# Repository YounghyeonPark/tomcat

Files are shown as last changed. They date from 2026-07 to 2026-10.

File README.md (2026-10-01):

# Project T.O.M.C.A.T.

**Tendon-Operated Mechanism for a Compliant Actuated Tomcat** — an open,
cat-sized quadruped whose joints are pulled by cables from motors in the body,
not driven by a motor at each joint.



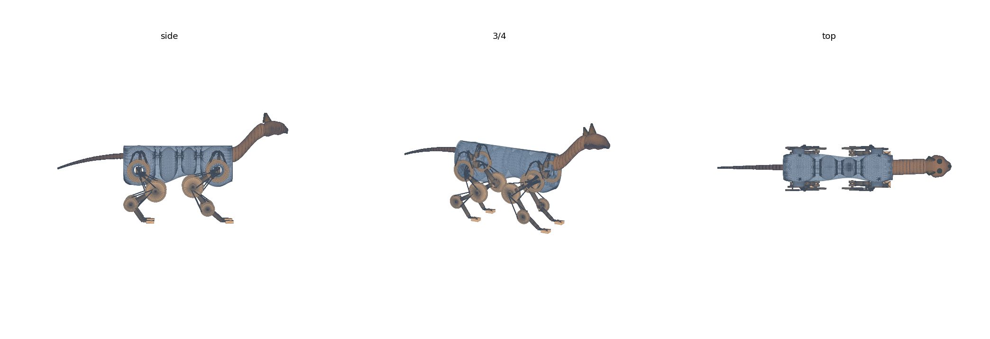
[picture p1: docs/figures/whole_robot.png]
the whole robot


## How a leg is driven

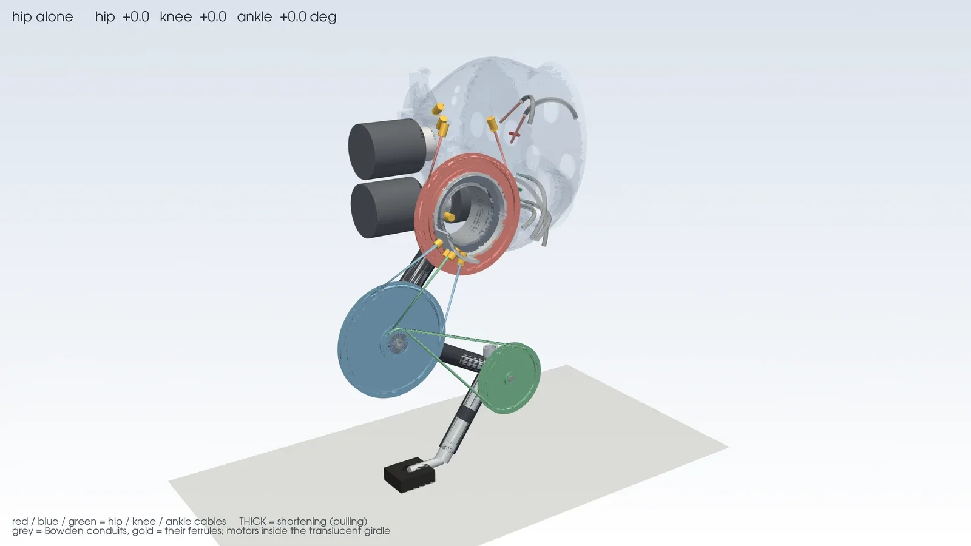
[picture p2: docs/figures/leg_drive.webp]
a hind leg's drive, in 3-D


Each joint is an antagonistic cable pair wound on one spool, so one motor
drives one joint both ways (red / blue / green = hip / knee / ankle; thick =
the cable pulling).

- **Motors in the body.** Each girdle holds its leg motors in two rows that
  straddle the hip, spools facing across it ([ADR-0114](docs/DESIGN_DECISIONS.md)).
- **Knee and ankle cables run along the hip axis**, through a hollow hip: the
  trunk carries a stub, the femur turns on it in two bearings, and the cables
  never cross the femur's path.
- **Bowden conduits** carry each cable from the body to the leg; friction is
  charged where the cable slides ([ADR-0112](docs/DESIGN_DECISIONS.md)).
- **A series spring (G3)** sits between each motor and its spool: a titanium
  planar flexure, 125 kN/m on the legs and 350 kN/m on the spine
  ([ADR-0107](docs/DESIGN_DECISIONS.md), [ADR-0117](docs/DESIGN_DECISIONS.md)).
- **An articulated, cable-driven spine** (3 segments, pitch and yaw) does the
  balancing sway and the mid-air righting.

| One leg, as parts | The trunk: 19 motors in four rigid bodies |
|---|---|
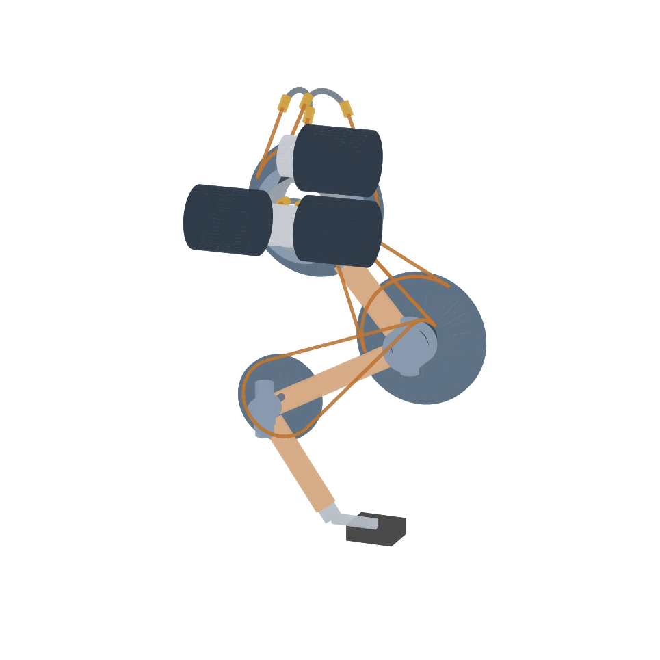
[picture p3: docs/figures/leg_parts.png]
leg detail
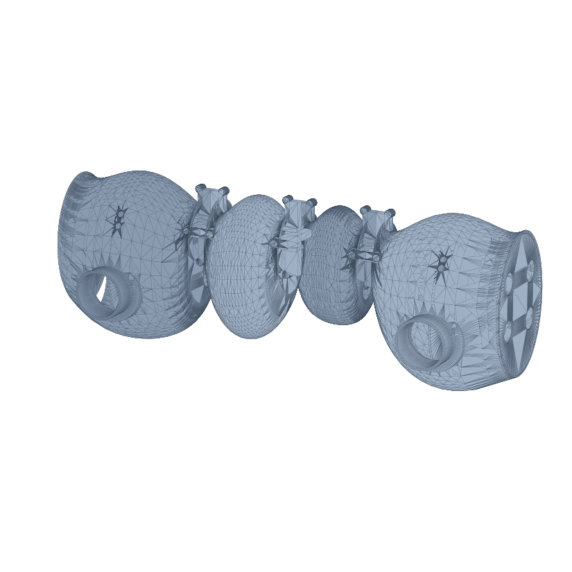
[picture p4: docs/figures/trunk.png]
trunk
|  |  |

## Key numbers

| | |
|---|---|
| Mass | **4.58 kg** (19 motors: 12 leg, 6 spine, 1 tail) |
| Trunk / hips apart | 372 mm / 270 mm |
| Joint moment arms (hip / knee / ankle) | 36 / 34 / 22 mm |
| Motor demand (peak / continuous) | 1.65 / 0.57 N·m per motor |
| Trot | 50 cm/s |
| Runtime, trotting | 18–24 min (~710 m) on a 300 g pack |
| Righting from upside down | ~1.0 s (simulated) |

Every number is computed from the live model, not typed in: the CAD, the
MuJoCo plant and the budgets all read `kinematics/src/tomcat_kin/params.py`.

## Status

**Modelling and design — no hardware built.** What is still uncertain, and
what closes it, is in [OPEN_RISKS.md](docs/OPEN_RISKS.md). The largest open
items: the motor (a GIM3505-9 is a proxy for size and mass; the spec it must
meet is in ADR-0100/0110), bench values for conduit friction and the G3 rates,
and a mock-up of the cable bundle that twists inside the hollow hip.

## Repository

| Path | Contents |
|---|---|
| `kinematics/` | `tomcat_kin`: kinematics, tendon maps, mass, gait, balance, MuJoCo plants, RL env |
| `mechanical/cad/` | build123d CAD: trunk, legs, hollow hip, drive, G3 flexure, head, tail, skin |
| `thermal/` | Rust crate: motor and girdle thermal duty |
| `tests/` | pytest suite (556 tests) |
| `docs/` | requirements, architecture, the ADR log, the progress log |
| `electronics/`, `firmware/` | not started |

```bash
pip install numpy pytest mujoco gymnasium build123d vtk matplotlib pillow
pytest tests --ignore=tests/test_mjcf_tendon.py   # conftest.py puts kinematics/src on the path
cd thermal && cargo test
python mechanical/cad/tomcat_assembly.py --render   # the whole-robot picture
python mechanical/cad/leg_drive_3d.py --hq          # the drive animation (1600x900, 30 fps)
```

> ⚠️ `tests/test_mjcf_tendon.py` needs ~19 GB as one process — run it in
> slices. The whole-robot render needs ~12 GB.

## Documents

- [Design decisions (ADR log)](docs/DESIGN_DECISIONS.md) — every choice, and why
- [Progress log](docs/PROGRESS.md) — the milestone-by-milestone record
- [Requirements](docs/REQUIREMENTS.md) · [Architecture](docs/ARCHITECTURE.md) ·
  [Principles](docs/PRINCIPLES.md) · [Open risks](docs/OPEN_RISKS.md)
- [Literature review](docs/LITERATURE_REVIEW.md) · [References](docs/REFERENCES.md) ·
  [Glossary](docs/GLOSSARY.md)

## License

[Apache License 2.0](LICENSE). The feline skeletal geometry derives from
Reighard & Jennings, *Anatomy of the Cat* (1901), public domain; third-party
material is listed in [NOTICE](NOTICE).

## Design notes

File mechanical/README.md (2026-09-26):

# mechanical/

Mechanical design for TomCat: leg geometry, joint/pulley design, tendon routing,
and bill of materials.

Scope:
- **Skeleton:** an articulated tendon-driven spine + 4 legs, 3 DOF each (hip,
  knee, ankle). The torso is *not* rigid — see [ADR-0006](../docs/DESIGN_DECISIONS.md)
  and NFR1/NFR2 in [../docs/REQUIREMENTS.md](../docs/REQUIREMENTS.md).
- **Spine:** serial segments allowing dorsoventral + lateral bend (and, ideally,
  axial twist for the righting reflex), with tendons routed to girdle motors.
- **Tail:** a **single-tendon** appendage — tension to curl/raise, loosen to
  relax (passive return); no precision (see [ADR-0007](../docs/DESIGN_DECISIONS.md)).
  Coarse inertial assist only — righting authority is in the spine + legs.
- **Tendon routing:** cable paths from torso-mounted motors over pulleys to each
  joint; sheaths, anchor points, and moment arms.
- **Compliance:** return springs and/or series-elastic elements per ADR-0002.
- **BOM:** motors, cables, pulleys, bearings, springs, fasteners.

## Review
- [DESIGN_REVIEW.md](DESIGN_REVIEW.md) — **first critical pass** over the whole
  mechanical design. Five findings, three major: the mass apportionment
  contradicts P1 (limbs over-budgeted, girdles under-budgeted), the 60/40
  front-heavy split is likely wrong once motors sit in their real clusters
  (which would move the M4 stability margins), and the **links are never
  structurally sized** — the femur sits at SF ≈ 1.0 in bending from its own
  offset tendon.

## Reference
- [reference/ANATOMY.md](reference/ANATOMY.md) — feline anatomy basis for the
  biomimetic geometry, citing **public-domain** sources (Reighard & Jennings,
  *Anatomy of the Cat*, 1901) — vertebral formula, digitigrade limbs, fore/hind
  asymmetry, thorax vs lumbar.

## CAD
- [cad/](cad/) — the build123d model, driven by `tomcat_kin`'s parameters: the
  whole robot (`tomcat_assembly.py`), the trunk with its 19 motors
  (`tomcat_trunk.py`), one leg as manufacturable parts (`tomcat_leg_detail.py`,
  STEP), the G3 flexure (`g3_flexure.py`, STEP), head, tail and skin. The first
  skeleton and packaging studies are kept there as history.

## Specs
- [ASSEMBLY_SPEC.md](ASSEMBLY_SPEC.md) — **how it is built**: fabrication method
  per part, joint assembly stack-up and fits, cable termination and
  re-tensioning access, assembly sequence. Also closes the combined
  bending+torsion and local-crushing checks (review F3/F5).
- [LEG_TENDON_SPEC.md](LEG_TENDON_SPEC.md) — leg tendon-drive spec for the
  pure-tendon legs (ADR-0003): moment-arm sizing that halves the ~1 kN cable
  tension to a ~500 N land transient, UHMWPE cable spec, pulley/bearing/routing
  and wrap angles (capstan friction), a static-hold brake, and the parameter
  table for `LegParams` / `TendonParams`.
- [SPINE_TAIL_SPEC.md](SPINE_TAIL_SPEC.md) — first-pass geometry & tendon-routing
  proposal for the 3-segment articulated spine (ADR-0006) and the single-tendon
  tail (ADR-0007): segment lengths, girdle placement, routing paths, moment arms,
  per-axis ROM, and the parameter table for `SpineParams` + `TailParams`, plus
  BOM/motor-count implications.

- [TACTILE_SENSING_SPEC.md](TACTILE_SENSING_SPEC.md) — **contact sensing and the
  paw structure** (ADR-0012), the prerequisite for closed-loop balance. Derives
  the force range, bandwidth and — the binding one — the **20 g/paw** distal-mass
  limit from the robot's own swing dynamics, and shows why the existing joint-end
  load cells cannot substitute.

## Status
Stub — CAD files and routing diagrams to be added. Mechanical review is the
gate for ADR-0002 (antagonistic vs. return spring) and torque budget feeding
ADR-0003 (actuator choice).

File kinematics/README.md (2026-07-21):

# kinematics/

Kinematics models, tendon mapping, and gait planning for TomCat.

Responsibilities (see [../docs/ARCHITECTURE.md](../docs/ARCHITECTURE.md)):
- **Leg kinematics:** forward/inverse kinematics (foot position ↔ joint angles).
- **Tendon map:** joint angle & stiffness ↔ per-motor cable length + tension,
  including moment arms (pulley radii), friction, and finite cable stiffness.
- **Antagonistic coordination:** split desired joint torque/stiffness across
  opposing tendons (or tendon + return spring) — see ADR-0002.
- **Gait planning:** foot/body trajectories for walk, trot, etc.

## Layout
- `src/tomcat_kin/` — the prototype package:
  - `params.py` — placeholder geometry / mass / tendon parameters (all TBD).
  - `leg.py` — planar 3R leg: FK, IK (both knee branches), Jacobian.
  - `tendon.py` — tendon map: angle↔cable, torque↔tension; antagonistic and
    spring-return modes (ADR-0002).
  - `torque_budget.py` — static worst-case joint/tendon/motor torque sweep.
- `demo.py` — runnable end-to-end example.
- Tests live in [../tests/](../tests) (`test_leg.py`, `test_tendon.py`).

## Run it
```
python kinematics/demo.py     # FK/IK round-trip, tendon resolve, torque budget
python -m pytest -q           # 17 tests (run from repo root)
```

## Status
Working single-leg prototype. **All parameters in `params.py` are placeholders**
— the torque-budget magnitudes are illustrative only until mechanical design
lands. The workspace sweep is also limited by the placeholder joint limits
(foot pitch is held at 0), so only part of the reachable area is currently
in-limit; revisit once real joint ranges exist.

Next steps: an articulated **spine model** (per [ADR-0006](../docs/DESIGN_DECISIONS.md))
so the leg base can curve, whole-body kinematics on top of it, a 3D
(frontal-plane abduction) leg, gait trajectory generation, and validating the
tendon map against measured cable friction/stretch.

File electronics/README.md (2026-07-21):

# electronics/

KiCad schematics and PCB layout for the TomCat control electronics.

Planned boards (see [../docs/ARCHITECTURE.md](../docs/ARCHITECTURE.md)):
- **Control board:** main compute / RT-MCU, IMU, host link, power regulation,
  e-stop.
- **Motor driver stage(s):** power stage per motor with current sensing;
  count depends on total DOF and antagonistic choice (ADR-0002).
- **Sensor conditioning:** tendon tension (load-cell amp) and joint-angle
  front-ends, per ADR-0004.

## Tooling
This repo has a `kicad-cli` skill available for ERC/DRC checks and BOM/Gerber
export once schematics exist. Read the skill's "Project gotchas" section before
trusting CLI ERC/netlist results.

## Status
Stub — no schematics yet. Blocked on actuator and sensing decisions
(ADR-0003, ADR-0004).

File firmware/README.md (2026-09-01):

# firmware/

Embedded control firmware for TomCat.

Responsibilities (see [../docs/ARCHITECTURE.md](../docs/ARCHITECTURE.md)):
- **Low-level (≥1 kHz):** per-motor position + tension control loops, safety
  limits (over-current, over-tension, thermal, e-stop → limp).
- **Sensor sampling:** motor current/encoder, tendon tension, joint angle, IMU,
  foot contact.
- **Comms:** telemetry up to the planner/host; setpoints down to motor loops.

> ⚠️ **"joint angle" is not a channel on the board.** `electronics/BOARD_OUTLINE.md` carries a **rotor** absolute encoder, current sense, a tension front-end (spine+hip/knee only) and an IMU — there is no joint encoder. Joint angle is *reconstructed* through the drivetrain (`wbc.joint_from_encoders`), and it needs the tension: without the ankle load cell the ankle angle is out by **1.09°**, rising to **6.08°** at the peak rating ([ADR-0077](../docs/DESIGN_DECISIONS.md), M72).

## Layout
- `src/` — implementation
- `include/` — public headers / interfaces

## Status
Stub. Target MCU, RTOS/bare-metal choice, and build system are open — see
ADR-0003 and ADR-0005 in [../docs/DESIGN_DECISIONS.md](../docs/DESIGN_DECISIONS.md).

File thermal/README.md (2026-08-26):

# Thermal duty — closing OPEN_RISKS R5

```
cargo test --release      # 17 assertions on the conclusions below
cargo run  --release      # the report
cargo run  --release --example winding   # the winding gradient
```

Built on **dualis 0.3**. The pack is a domain on the same bus as the girdle, so
`Simulation::advance` runs the kernel's conservation audit every step and the runtime
is **emergent** (42 Wh at 83.6 W -> 30.17 min, against `power.py`'s 30.16). One test
feeds it a deliberately leaky pack and asserts the audit **refuses** it — an audit
that cannot fail is decoration.

## Why this is Rust, in a Python repo

It uses [`dualis-thermal`](https://crates.io/crates/dualis-thermal) — lumped masses,
conduction, radiative and convective loss. Nothing else here needs Rust, and nothing
here depends on this crate: it is a leaf. The 332 Python tests do not require a
toolchain, and `tests/test_thermal_constants.py` is the only link, guarding the
handful of numbers copied across.

## What it answers

[ADR-0021](../docs/DESIGN_DECISIONS.md) checked the motor **electrically** — 2.79 A
peak against a 4.19 A rating, 0.89 A RMS against 1.60 A — and called it comfortable.
That is not the thermal question. The thermal question is whether the heat can
*leave*, and R5 sat as "gated on hardware" because of it. It is not gated on
hardware.

> ⚠️ **Every number below rose in M40** ([ADR-0045](../docs/DESIGN_DECISIONS.md)).
> `power.py` computed copper loss as `I²R_pp` where balanced three-phase is
> `3I²R_ph = 1.5×` that. Per-motor dissipation went **3.50 → 5.25 W** and the whole
> chain moved with it. Superseded figures are struck through.

| front girdle, 6 motors | continuous | one battery |
|---|---|---|
| trot, polished | **155.2 °C** ~~113.7~~ | 78.3 °C ~~67.1~~ |
| trot, anodised | **96.1 °C** ~~74.9~~ | **70.2 °C** ~~59.7~~ |
| stand w/o brake, polished | **183.9 °C** ~~134.1~~ | 97.2 °C ~~85.7~~ |
| stand w/o brake, anodised | **110.2 °C** ~~85.4~~ | 84.5 °C ~~72.5~~ |

⚠️ **The headline conclusion is overturned.** This file used to say *"anodised, it is
safe because its own equilibrium is ~75 °C"*. It is **96.1 °C**, and the
battery-limited anodised trot lands at **70.2 °C** — on the wrong side of the 70 °C
line it was comfortably inside before.

**The battery is still the thermal protection, and it is now doing more of the work,
not less.** A bare girdle's effective time constant (~49 min) exceeds the runtime it
can be fed for (24 min), so the robot still runs out of energy before it overheats.
Tether it, or hot-swap the pack, and the protection is gone — and now the anodised
case needs it too.

⚠️ **Forced air moves from "would reopen it" to "required for continuous
operation".** At `h = 15` the anodised girdle settles at **72.7 °C**; at `h = 25`,
58.2 °C. Still air cannot hold a continuous trot at any finish.

⚠️ **Corrected.** The 53 min first published came from
`LumpedMass::time_constant`, which is `C/(hA)` — **convection only**, so it returns the
same number for a polished and an anodised body. Measured from the transient:
**46.6 min polished, 25.6 min anodised.** The temperatures were always computed with
radiation and did not move; the *mechanism* was misstated. Anodised, the girdle does
not outlast the pack at all — it is safe because its own equilibrium is ~75 °C.

Three things follow that were not visible from the electrical check:

- **Anodising is worth ~59 K** (~~39 K~~ — the lever *grew*, because radiation goes
  as the fourth power of temperature and M40 pushed the operating point up).
  Radiation is the same order as still-air convection here, so emissivity
  0.09 → 0.90 remains the cheapest lever available. ⚠️ **It is no longer
  sufficient on its own** — see the overturned conclusion above. Surface finish is a
  thermal parameter here, not a cosmetic one.
- **Centralising the motors costs 38 % of the rejection area** (486 → 302 cm²).
  This is the first measured place where design principle **P1 charges** rather
  than pays.
- **Standing without the brake is the worst case** — worse than trotting, because a
  cable can only pull. ADR-0021 reached the same conclusion about the brake from
  runtime; this reaches it from heat.

## The winding

`winding.rs` answers what this file used to warn about. dualis 0.3's `ThermalNetwork`
(from [upstream #2](https://github.com/YounghyeonPark/dualis/issues/2)) makes
**winding → stator → housing → girdle → air** expressible:

| | winding | stator | skin |
|---|---|---|---|
| polished, continuous | **166.7 °C** ~~121.4~~ | 160.9 ~~117.5~~ | 155.2 ~~113.7~~ |
| anodised, continuous | **107.6 °C** ~~82.6~~ | 101.8 ~~78.7~~ | 96.1 ~~74.9~~ |

**+11.5 K** (~~+7.7 K~~), the same for both finishes — the finish sets where the
stack sits, the joints set the spread. The gradient scales with dissipation, so M40
moved it too. The joints are `[assumed]`, so the sweep is the result rather than any
single number.

## ⚠️ Limits

The joint conductances set the entire gradient and are guesses. Copper loss is the only
source (inherited from ADR-0021), so the real dissipation is higher. The girdle
envelope, `h`, and both emissivities are `[assumed]` — every result is swept rather
than stated once.

**This does not close [R1 or R2](../docs/OPEN_RISKS.md).** Simulation checks the
model; only a measurement checks the inputs.

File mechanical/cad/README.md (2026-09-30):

# mechanical/cad/

## Current model (M126)

the whole robot

The robot as it is designed today. Every script reads `tomcat_kin`'s
`params.py`, so CAD and simulation cannot drift; each writes its own STEP /
PNG when run (`python mechanical/cad/<script>.py`; STLs are git-ignored).

| script | what it draws | output |
|---|---|---|
| `tomcat_assembly.py` | the whole robot: four legs on the trunk, stance pose | `tomcat_whole.png` |
| `tomcat_trunk.py` | four rigid bodies, 19 motors; each girdle is two rows straddling its hip, spools facing across it (M123), each row motor + G3 + spool | `tomcat_trunk.png`, `_side.png` |
| `tomcat_leg_detail.py` | one hind leg as parts: tubes, a HOLLOW hip (hub on 40 × 50 bearings over the trunk's stub, ADR-0114), clevis knee and ankle, 36/34/22 mm sheaves (ADR-0103), the Bowden drive | `tomcat_leg_detail.step`, `.png` |
| `g3_flexure.py` | the series-elastic flexure between rotor and spool, leg and spine variants (ADR-0107/0111) | `g3_flexure.step`, `g3_flexure_spine.step`, `.png` |
| `tomcat_head.py`, `tomcat_tail.py`, `tomcat_skin.py` | head and neck, tail, the skin cover | `.png` |
| `tendon_exit.py`, `leg_drive_3d.py` | the leg drive in 3-D, spool to anchor (ADR-0112/0114), and its animation | `leg_drive_3d.gif`, `_still.png` |
| `girdle_inertia.py`, `link_inertia.py`, `mass_closure.py` | the masses and inertias `params.py` carries, derived from the drawn parts | printed |

Body **4.579 kg**, 19 motors (the GIM3505-9 is a PROXY for envelope and mass;
the spec it must meet is in ADR-0100/0110).

⚠️ **Everything below this line is HISTORY** -- the July skeleton and
packaging studies (`tomcat_skeleton.py`, `tomcat_packaging.py`,
`render_views.py`) and the two-girdle study (`tomcat_girdle.py`) that
`tomcat_trunk.py` replaced in M88. Their scripts and renders are kept as
the record of how the layout was reached; their numbers (motor clusters,
girdle boxes, 4.31 kg) are superseded and they are not re-exported.

---

## History: the skeleton and packaging studies (July 2026)

The first **real 3D geometry** for T.O.M.C.A.T. — a parametric skeleton model
built with [build123d](https://github.com/gumyr/build123d) (code-CAD on the
OpenCascade kernel) and exported to STEP.

Its defining feature: it imports the **same parameters the `tomcat_kin`
simulation uses** (`LegModel`, `DEFAULT_LEG`, `DEFAULT_SPINE`), so the CAD and
the simulation cannot drift apart — change a link length in
`kinematics/src/tomcat_kin/params.py` and this model follows on the next run.
The four legs are posed by solving the leg **IK** for feet planted on the ground.

## Skeletal detail

The skeleton is no longer a capsule massing model — it implements bone **form**,
joint **structure** and joint **axis orientation**, following the public-domain
[ANATOMY.md](../reference/ANATOMY.md) reference and the cat vertebral formula
(C7 / **T13** / **L7** / S3 / Ca~20):

| Feature | How it is modelled | Why it matters |
|---|---|---|
| **Long bones** | shaft + expanded **condyles** at each end | the flare is where a joint bearing seats and a pulley gets its arm |
| **Joint axes** | every actuated joint drawn as a **cylinder along lateral y** | shows structure *and orientation*, not just a blob |
| **Hip / shoulder** | ball (3-DOF in a cat; we actuate the sagittal DOF only) | honest about what is and isn't actuated |
| **Vertebrae** | ~20 presacral bodies with **spinous + transverse processes** | thoracic spines sweep **back**, lumbar **forward**, meeting at the anticlinal vertebra |
| **Actuated spine joints** | only **3**, highlighted in a darker tone | the reader can count what ADR-0006 actually drives |
| **Ribcage** | 8 **C-curved** rib pairs to a **sternum** | encloses a real volume, not decorative rings |
| **Scapula** | sagittal blade sloping down-forward, glenoid at its tip | cats have **no functional clavicle** — the forelimb hangs from this mobile blade, which is also its righting contribution (ADR-0007) |
| **Pelvis** | ilium blade up-forward + ischium back | anchors the hind limb and the tail |
| **Neck / skull / tail** | cervical curve, cranium + muzzle, tapering caudal chain | completes the form |

The legs are **digitigrade** — a 4-link chain (femur/tibia/metatarsus/paw) with 3
actuated joints + a passive paw. The model is **fore/hind asymmetric**: the hind
**stifle bends forward** (negative range) and the fore **elbow bends backward**
(positive range), each derived from that leg's own joint limits via
`LegModel.default_knee`. **Both paws point forward**, as in a cat.

### Stance — crouched, not straight

The limbs stand at **~63 % of leg reach** (hip-to-paw / total reach), matching a
standing cat's ~55–65 %; an earlier revision sat at 70 % and read as
noticeably straight-legged. Deepening the crouch turned out to be nearly **free**:
with a vertical support force the **hip** torque depends only on the foot's
horizontal offset, and the **hock** torque is fixed by the paw geometry, so a
deeper crouch loads **only the stifle** (0.14 → 0.34 N·m at trot) — far below the
binding hip/hock. Stability margin is unchanged and ~10° of joint-limit margin
remains over the gait cycle, so the gait adopted the same stance.

A geometry bug surfaced while checking this: the forelimb hangs from the
scapula's **glenoid**, which sits ~17 mm *below* the hip, but every limb was
solving for one global ground drop — so the **front paws sat 17 mm underground**.
Each limb now solves for its own mount-to-ground distance.

### Two component placements this detail justified

1. **The spinous process height *is* the spine tendon moment arm.** The 30 mm arm
   in `SpineParams` was an abstract pulley radius; it is now the dorsal process
   the tendon actually bears on, so CAD and parameter agree by construction
   (`SPINOUS_H` is read from `DEFAULT_SPINE.joint_moment_arm`).
2. **The battery / electronics moved *inside* the thoracic basket.** The earlier
   model put a "mid-body bay" box in the belly with no structural justification.
   The ribcage is the natural home: protected, central, low, and near the CoM.

## Files
- `tomcat_skeleton.py` — the parametric model (source of truth).
- `tomcat_skeleton.step` — CAD interchange (open in any MCAD tool).
- `tomcat_skeleton.png` — rendered preview (below).
- `tomcat_skeleton.stl` — mesh for printing/quick view; **git-ignored** (2 MB,
  regenerated by running the script).

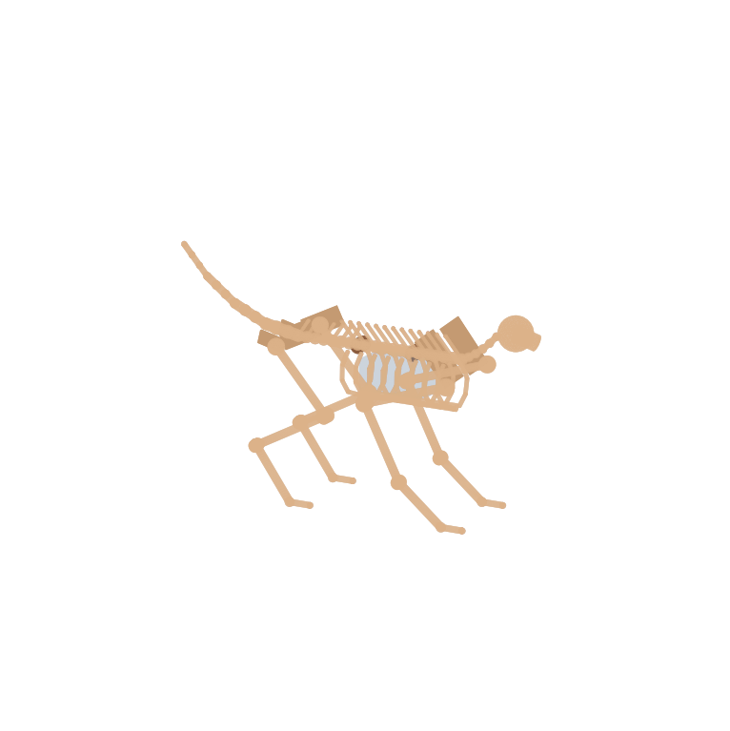
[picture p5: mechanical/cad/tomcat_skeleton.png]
skeleton render


## Run
```
pip install build123d matplotlib      # if not already present
python mechanical/cad/tomcat_skeleton.py
```

## Dimensions (from the model)
| Item | Value | Source |
|---|---|---|
| Hind-leg links (femur/tibia/metatarsus/paw) | 90 / 95 / 70 / 25 mm | `DEFAULT_LEG` (digitigrade) |
| Fore-leg links (humerus/radius/metacarpus/paw) | 100 / 90 / 65 / 25 mm | `DEFAULT_FORELEG` (columnar) |
| Actuated joints per leg | 3 (hip · stifle · hock) + passive paw | `LegParams` |
| Spine segments (tapered) | 75 / 65 / 55 mm (195 total) | `DEFAULT_SPINE` |
| Hip / body height (standing) | 170 mm | IK stance target, ~63 % extension |
| Track width (L/R limbs) | 96 mm | ❓ placeholder |
| Vertebrae drawn / actuated spine joints | 20 (T13 + L7) / **3** | `ANATOMY.md` / ADR-0006 |
| Spinous process height = spine tendon arm | 30 mm | `DEFAULT_SPINE.joint_moment_arm` |
| Overall bounding box | 427 (L) × 115 (W) × 262 (H) mm | computed |

## Scope / honesty
This is a **skeletal model**, not a manufacturing model:
- Bone *form* and joint *axes* are modelled, but there are **no fasteners,
  bearings, tolerances or fabrication features** — nothing here is machinable
  as drawn. That is review finding **F5**, still open.
- Left/right limbs are placed at a chosen track width; the underlying kinematics
  is still the **2D sagittal** model, so there is no true frontal-plane geometry
  yet — the top plan is a projection, not a solved 3D pose.
- The kinematics model has **no scapula** (it mounts the forelimb on the girdle
  frame), so CAD and model differ slightly at the shoulder *by design*: the model
  is the authority for stability, the CAD for form.
- Body width, bone/vertebra radii, girdle size, tail shape and every dimension
  driven by `params.py` remain **placeholders**.

## Packaging model — motors · tendons · joints

`tomcat_packaging.py` extends the skeleton with the *internal* layout: it places
**one motor per driven tendon**, clustered in the girdles (P1), routes **tendons**
from each motor spool along the limb/spine to the joint it drives, and puts
**pulleys** at every joint (hip/knee/ankle + vertebrae) at their real moment-arm
radii. The girdle housings are **sized to enclose the motor banks** — so it is a
genuine fit check, not a fixed box.

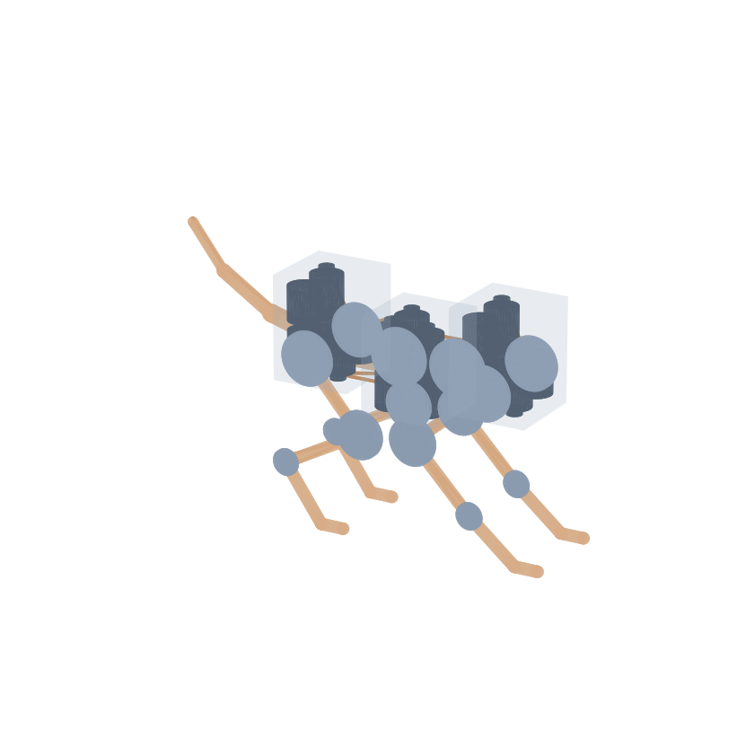
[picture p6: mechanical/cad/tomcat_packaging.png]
packaging render


`python mechanical/cad/tomcat_packaging.py` → `tomcat_packaging.step` + `.png`.
Render colours: bone = tan, **motor = slate**, **tendon = copper**, pulley = steel,
girdle = translucent.

### Multi-view renders

`render_views.py` produces legible three-view figures (side elevation · top plan ·
isometric) for both models — clearer than the single iso the build scripts emit:

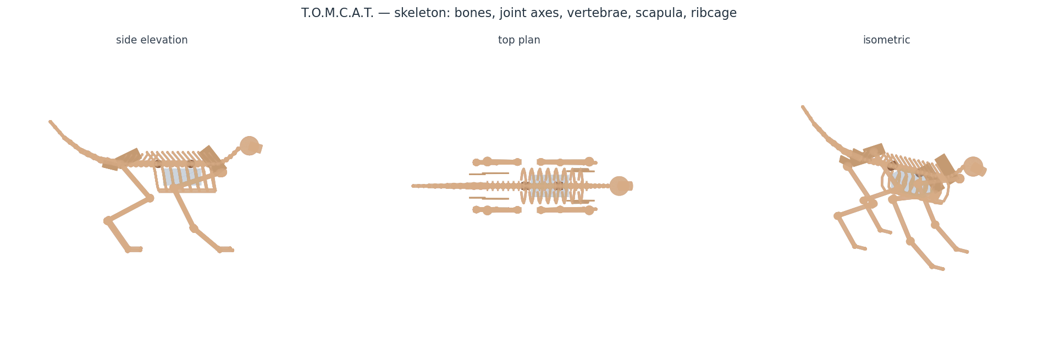
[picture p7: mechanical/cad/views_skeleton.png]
skeleton views


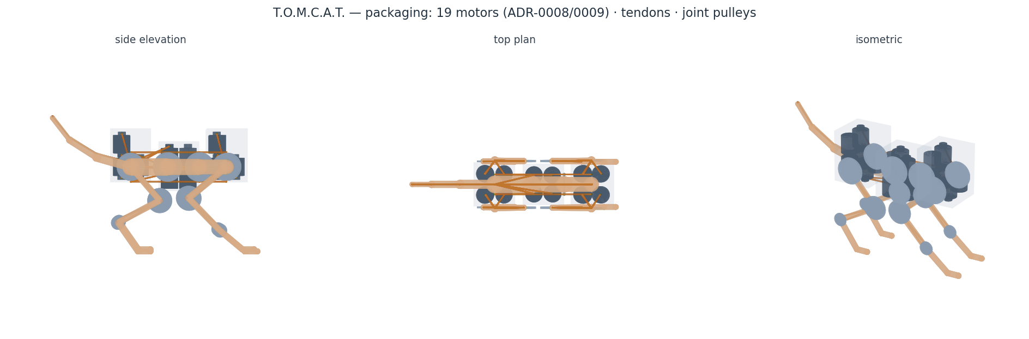
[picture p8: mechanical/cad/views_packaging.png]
packaging views


### Fit findings — re-packed for **19 motors** (ADR-0008 + ADR-0009)

[ADR-0008](../../docs/DESIGN_DECISIONS.md) cut the count 24 → **16** (one
variable-radius-pulley motor per DOF) and the
[down-select](../../docs/notes/motor-downselect.md) replaced the Ø16 × 28 mm
placeholder with a realistic **Ø36 × 26 mm, ~74 g pancake QDD** module. Both
changes invalidated the earlier F4 packing, so it was redone.

⚠️ **Re-packed again for the REAL motor.** The surveyed part is
**Ø34.5 × 36.1 mm** — very close in diameter to the placeholder but **39 %
longer**. Because the banks stack along z, that goes straight into girdle
**height**: 88 → **108 mm**. Width is unaffected and still clears the 96 mm
track, so nothing collides — but it confirms the earlier F4 verdict that the
torso is, honestly, a motor box.

[ADR-0009](../../docs/DESIGN_DECISIONS.md) then added the **spine LATERAL bend**
DOF, taking the count **16 → 19**. The three extra motors join the spine bank in
the mid-body bay, which is why that bay grew and now packs 2 × 2 rather than
2 × 1 — seven motors stacked two per layer would tower 152 mm out of a 113 mm-wide
cat.

| Result | Value |
|---|---|
| Motors | **19** — 12 leg DOF (3/leg) + 3 spine dorsoventral + **3 spine lateral** + 1 tail |
| Motor envelope | **Ø34.5 × 36.1 mm, 131.7 g** `[sourced: SteadyWin GIM3505-9 + driver]` — replaces the Ø36 × 26 mm / 74 g class target, which does not exist ([reality check](../../docs/notes/motor-reality-check.md)) |
| Shoulder girdle | **82 × 86 × 108 mm** (6 motors, 2 per layer) |
| Pelvic girdle | **82 × 86 × 108 mm** (6 motors) |
| Mid-body bay | **82 × 82 × 100 mm** (3 spine + 3 lateral + 1 tail, 2 × 2 per layer) |
| Width vs 96 mm leg track | **86 mm — still fits** |
| Overall | 426 × 113 × 281 mm |

**Two layout decisions this forced:**

1. **Upright, stacked motors.** Real Ø36 pancakes only fit ~2 per layer inside a
   cat torso, so each bank stacks in z. Girdles are now 88 mm tall — the torso is
   frankly a motor box, which is the honest consequence of P1 centralization.
2. **A third, mid-body bay.** The spine + tail bank no longer fits in the pelvic
   girdle without stretching it to 173 mm (over half the 195 mm spine). It moved
   to the **belly between the girdles** — otherwise empty volume, still
   "centralized" per P1, and a natural spot for the battery too.

> ⚠️ **This third cluster is not in [ADR-0005](../../docs/DESIGN_DECISIONS.md)**,
> which specifies shoulder + pelvic girdle clusters and a tail node on the CAN-FD
> bus. A mid-body node is a small topology change that should be reflected there.

<details><summary>Superseded: the original 24-motor F4 finding</summary>

The first layout laid motors **axis-along-Y**, so each body + spool projected
sideways from banks at y = ±42 — a **142 mm** girdle against a 96 mm track, and a
91 mm-tall pelvis. Standing them upright fixed it (142 → 87 mm) at 24 motors of
the old small placeholder. The numbers above supersede that pass.
</details>

## Next
A real solid-modelling pass with actual motor part solids, bearing/pulley
hardware, cable anchors, and mounts — turning this layout study into parts and a
BOM (review F5). The girdle-packaging finding (F4) is resolved above.

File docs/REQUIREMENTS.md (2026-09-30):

# TomCat — Requirements

Status: **DRAFT** — targets are placeholders to be confirmed. Open questions are
tracked inline as `❓`.

Grounded in the two [design principles](PRINCIPLES.md): (P1) tendon-driven,
centralized multi-motor actuation, and (P2) a feline form whose whole body may
curve.

## 1. Goals

- G1. Quadruped locomotion with cat-like agility (walk, trot, and eventually a
  controlled leap/land).
- G2. Tendon-driven joints with motors centralized in the body girdles to
  minimize limb inertia (P1).
- G3. Passive compliance / shock absorption at each joint.
  ✅ **SIZED by ADR-0047 (M42), banded by ADR-0048 (M43), and CONFIRMED FROM A
  SECOND DIRECTION by ADR-0049 (M44): a 150-200 kN/m series-elastic element at the
  hip and knee**, **175 kN/m** the point value to quote. The cable alone gives the
  hip **1295 N·m/rad** — **5.2×** the stiffness at which ADR-0026's balance
  harness wound up and fell — so ADR-0026's *"balance needs compliant legs"* is a
  **hardware** requirement, not a controller gain. At 175 kN/m the hip and knee land
  at **133 / 104 N·m/rad**, inside ADR-0026's 80-150 window.
  ✅ **And under FOOT-FORCE control the element is what makes the robot stand at
  all** (ADR-0049): at 175 kN/m it stands to 0.006° of trunk tilt, with the bare
  cable it **inverts**, with no elasticity it leans 14.6°. Two independent
  arguments — balance compliance and force control — two different failure
  modes, the same part.
  ⚠️ **Not at the ankle**, which fails two other ways: a single-tendon joint has
  **no restoring stiffness** from its cable (**41.0** N·m/rad measured, 0.3 of it
  the ADR-0002 Option-B return spring), and ADR-0049 found its **moment arm reverses
  sign inside the ROM at every anchor angle** — so the one direction it can pull is
  not a fixed direction in joint space.
  ✅ **ADR-0050 (M45) settled that: the ankle takes ADR-0002 Option A, an
  antagonistic pair in a CAPSTAN construction** (both cables to one anchor, opposite
  wraps — mirroring the way the hip and knee do it leaves a 60° dead band with the
  stance hock inside it). The deciding argument was **kinematic reach**, not
  stiffness: the trot commands the ankle **+62.4° above its reference during SWING**
  and Option B has no actuator that pulls that way. Option A doubles the ankle's
  restoring stiffness too (11.4 → 22.5 N·m/rad), though that is still far below
  ADR-0026's 80 floor — the ankle cables are the longest, so `EA/L` is lowest.
  ⚠️ Numbers published here before: M42's 1269 / 39.7 / 128-91 and M43's 1304 / 53.9
  / 136-107. Each routing repair re-cut the cable runs and moved them. The
  **conclusion and the ~175 kN/m target survived all three**.
- G4. Energy-efficient movement compared with a direct-drive baseline.
- G5. An articulated, tendon-driven spine so the body can arch and bend
  laterally like a real cat (P2). ✅ **MET** — 3 sagittal + 3 lateral joints,
  built and measured ([ADR-0062](DESIGN_DECISIONS.md)).
  ⚠️ **The "and twist" clause was withdrawn by the project owner (M66,
  [ADR-0071](DESIGN_DECISIONS.md)).** Axial roll was specified by ADR-0006 and
  deferred; the only use ever recorded for it was G6's righting, which went with
  G6. Nothing else in the project asked for it, so the spine is complete at
  **6 DOF**.
- ~~G6. Mid-air righting: reorient during a fall to land feet-first, via spine
  axial-twist + legs, with a coarse single-tendon tail assist.~~
  ⚠️ **WITHDRAWN by the project owner (M66, [ADR-0071](DESIGN_DECISIONS.md)).**
  Measured, the robot rights from fully inverted in **2.14 s** — a fall from
  **22.5 m**, against the 0.247 s a 0.3 m drop allows. ⚠️ **And 2.14 s was
  the optimistic plant**: give the spine the drivetrain G3 requires and it takes
  **10.10 s**, a fall from **500 m** (M70, [ADR-0075](DESIGN_DECISIONS.md)). Every route to closing that
  was measured and closed: trajectory design bought 1.5×, the axial DOF the goal
  names is **negative**, and feedback buys direction but not speed.

## 2. Functional requirements

| ID | Requirement | Priority |
|---|---|---|
| FR1  | Drive N tendons via rotary motors with closed-loop position control. | Must |
| FR2  | Measure and closed-loop control cable **tension** per driven tendon. | Must |
| FR3  | Sense joint angle (directly or inferred from cable displacement). | Must |
| FR4  | Execute a parameterized gait to produce forward walking. | Must |
| FR4b | Execute a diagonal **TROT** (dynamic gait) — the primary locomotion mode. | Must |
| FR9  | Actuate the spine to bend (dorsoventral + lateral) via tendons. | Must |
| FR9b | Command lateral spine sway toward the support side, in phase with the gait. | Must |
| FR10 | Coordinate spine curvature with leg motion (whole-body posture). | Should |
| ~~FR11~~ | ~~Detect a fall and reorient (tail + spine twist) to land feet-first.~~ ⚠️ **WITHDRAWN with G6** ([ADR-0071](DESIGN_DECISIONS.md)). | ~~Should~~ |
| FR5  | Detect and recover from a foot slip / unexpected ground contact. | Should |
| FR12 | Sense **per-foot contact and normal force** (≥1 kHz) for closed-loop balance. | Must |
| FR6  | Report telemetry (per-motor current, tension, angle) over a host link. | Should |
| FR7  | Support a calibration routine for zeroing tendon tension and joint range. | Must |
| FR8  | Enter a safe, limp state on fault (over-current, over-tension, e-stop). | Must |

## 3. Non-functional / performance targets  ❓ *confirm with mechanical design*

| ID | Target | Value (placeholder) |
|---|---|---|
| NFR1  | Degrees of freedom per leg | 3 (hip, knee, ankle)|
| NFR2  | Spine segments (serial, tendon-driven) | **3** (ADR-0006) |
| NFR2b | DOF per spine segment | **2** — dorsoventral + lateral (ADR-0006/0009) |
| NFR2c | Total actuated DOF (12 legs + 6 spine)  | **18** — ⚠️ **was 19 with a tail motor, reduced by [ADR-0071](DESIGN_DECISIONS.md) (M66)**: the tail's only cited purpose was G6's righting assist, and G6 is withdrawn. ✅ **18 of 18 BUILT** (M57, [ADR-0062](DESIGN_DECISIONS.md)): 12 leg + 6 spine, and the 18-DOF body stands. The **tail is owed** — it has a motor in the mass budget and no parameters, joint or body anywhere. ⚠️ The earlier "confirmed against the routed drive (M37)" was a check of the *motor count*, not of actuated DOF: until M57 no MuJoCo model had more than **15**, and none had a **sagittal** spine joint at all. |
| NFR2d | Tail actuation (coarse assist, no accuracy) | 1 tendon + passive return |
| NFR2e | Spine LATERAL bend ROM (per segment) | **±15°** (ADR-0009; gait commands 11°, so ~4° spare) |
| NFR2f | Spine lateral **slew rate** (per segment) | **≥ 119 °/s** — sized to a FAST reference manoeuvre (righting / future dynamic gait), **not** the 5 s crawl, which needs only ~29 °/s (ADR-0010) |
| ~~NFR2g~~ | ~~Paw–ground friction μ ≥ 0.70~~ | **WITHDRAWN (ADR-0010).** The resolved per-foot demand is **μ ≈ 0.055**; friction was never the binding constraint. Any sane pad meets it. |
| NFR2h | Statically stable walk speed | **~1.1 cm/s** (crawl), limited by **TIPPING** (ZMP), not friction. Faster requires a *dynamic* gait — ADR-0010 |
| NFR2i | Dynamic (ZMP) stability margin, CRAWL | **> 0** at every phase; currently **+6.4 mm** ⚠️ small |
| NFR2j | **TROT** speed (the locomotion mode) | **~50 cm/s** default — slowed from 67 cm/s by ADR-0020: the spine's balance assist costs ground friction as `1/stance²`, and at 0.3 s it exceeded a realistic floor. Motor-thermally capable of ~96 cm/s on a better floor. |
| NFR2k | Trot roll oscillation | **bounded** — roll-rate drift ≈ 0 per cycle. ⚠️ Requires `nominal_foot` **x ≈ 0.00214 m**, re-tuned from 0.005 by **ADR-0046 (M41)**: the balance point is set by where the CoM sits relative to the diagonal, so it moved when the measured leg masses landed. At the old 0.005 the drift is **−0.180 rad/s per cycle** — divergent. The crawl's 0.05 m still falls in one stride. |
| NFR8  | Paw force sensing range / survival | **0–35 N** measured, **≥100 N** survival (×2.5 land transient), ≤0.4 N resolution, ≥1 kHz (ADR-0012) |
| NFR10 | **Disturbance rejection envelope** (trot) — *reduced-order capability* | **52.7 mm** DCM error, fixed-point with real latency AND the actuation ramp. Superseded figures: 74 → 33 → 90 → 59 → 57 (ADR-0017, 0.3 s stance) → 53.9 (ADR-0020, trot slowed to 0.4 s) → **52.72** (ADR-0025, sway CoM correction). ⚠️ This is the 1-D reduced-order figure; **measured** in closed-loop simulation it is **25.6 mm** in the worst direction (ADR-0037) — see NFR15. |
| NFR12 | **Balance PIPELINE latency** (contact → command)  | **≤ 7.5 ms** — contact 1.0 + estimation 5.0 + transport 1.0 + compute 0.5 (ADR-0016). Re-cast from a whole-loop ≤20 ms: whole-loop is ~45 ms and **37 ms of it is the leg moving**, not electronics. ✅ **MET — measured on the plant** (M73, [ADR-0078](DESIGN_DECISIONS.md)): at 1 kHz the 7.5 ms budget costs **2 N** (74 against a 72 N baseline) and 0.01° of tilt; at 133 Hz it costs 47 N and 0.91°. The failure boundary is **15–20 ms**, so the re-cast from 20 ms is what buys the margin. |
| NFR13 | Lateral shove rejected — *reduced-order capability* | **0.41 m/s** — the physical reading of NFR10 via xi = c + c_dot/omega. ⚠️ This is what the robot ACHIEVES; **NFR15 is what it must achieve** (ADR-0017). |
| **NFR15** | **Disturbance cases the robot MUST survive**  | a **15 N / 0.1 s push** (48 mm), an **unexpected 40 mm step**, and a **10° lateral slope**. A 30 N shove (96 mm) is explicitly OUT of scope. Met with ~19 % margin **in the reduced-order model** (ADR-0017). `[assumed]` scenarios. ⚠️ **Not yet DEMONSTRATED in simulation, and by a wider margin than long recorded.** The MuJoCo harness reaches **25.6 mm** worst-direction — but ⚠️ **ADR-0040 (M35) established that is a SURVIVAL figure** (the trial passes if the robot does not fall inside the horizon), whereas the viable set is a **RECOVERY** bound. Like-for-like the recovery envelope is **1.5 mm**: the shipped controller ends its certified 25.6 mm trial 26.2 mm off its support. ⚠️ The previously quoted **"86 % of optimal" is WITHDRAWN** — it compared the two criteria. Cause diagnosed: the placement law has no term removing a *persistent* DCM offset, so it settles into a biased limit cycle (the ADR-0013 "walking away sideways" mode). ✅ **Still ACHIEVABLE** (ADR-0033): the exact viable set is **62.7 mm**, past the 48 mm required, and the reduced-order model is *conservative* on the spine term. ⚠️ **But one contradiction is open** (M36): at a 0.117 s stance the harness genuinely recovers from 42.2 mm against a 39.5 mm exact bound, so either that bound or the simulation is wrong. |
| **NFR16** | **Floor friction μ** (reinstated) | **≥ 0.70** — the spine's balance action is INTERNAL motion, so shifting the CoM against the planted feet costs ground reaction: 0.71 for full spine authority + 0.145 for the gait. ⚠️ ~~ADR-0010 withdrew this~~ — correctly, for the *crawl crossover*; it returns for a *different mechanism*. ⚠️ **Relaxed by ADR-0034:** re-derived on the exact viable set, NFR15 is met from **μ ≥ 0.6**, so 0.70 carries ~20 % margin rather than none. |
| NFR14 | **Leg spare foot speed** (for corrections) | **≥ 4.1 m/s** — the DOMINANT term in the balance loop. Ceiling is 5.93 m/s, nominal swing uses 1.83 (ADR-0016). |
| NFR11 | **DCM estimation accuracy** | **≤ 3 mm** — a steady bias becomes a PERMANENT lateral offset amplified 3.2× (ADR-0013). Sharpens NFR8/ADR-0012. |
| NFR9  | **Paw sensor mass** | **≤ 20 g per paw** — binding via SWING INERTIA, not mass: 20 g costs top speed 120→96 cm/s, 40 g exceeds the motor's continuous rating (ADR-0012) |
| NFR3  | Control loop rate (tension/position) | ≥ 1 kHz |
| NFR4  | Gait / trajectory update rate | ≥ 100 Hz |
| NFR5  | Mass (total) | ✅ **4.579 kg — M126 ([ADR-0117](DESIGN_DECISIONS.md))**: the spine's G3 at 350 kN/m, 10 g lighter; motor peak 1.647 N·m. ✅ 4.589 kg — M124 ([ADR-0115](DESIGN_DECISIONS.md))**: the hub lightened, the bearing at its catalogue 22.8 g, the fore radius Ø14 (it was SF 1.76 at landing — never checked). Motor peak 1.650 N·m. ✅ 4.605 kg — M123 ([ADR-0114](DESIGN_DECISIONS.md))**: the hollow hip, +26 g a leg (a hub on two 40 × 50 bearings); the trunk is 21 mm shorter (each girdle is two rows straddling its hip). Motor peak 1.656 N·m, the hind and fore hips tied. ✅ 4.501 kg — M122 ([ADR-0112](DESIGN_DECISIONS.md))**: the legs drop the hip via, the return spring and the anchor pins (−13 g each); the trunk is 30 mm longer (spine joint 0 moved forward). Motor peak 1.623 N·m. ✅ **4.554 kg — M120 ([ADR-0111](DESIGN_DECISIONS.md)) folds in the eighteen G3 flexures, 85.6 g**, drawn thinner (the stop moved into the spool) so every row fits the trunk without lengthening a body; motor peak 1.859 N·m. ✅ **4.3041 kg — FOLDED IN by ADR-0046 (M41)**; `params.py` now carries it. ⚠️ **4.31 kg** — raised again by **ADR-0043 (M38)**: drawn as manufacturable parts a leg is **167 g**, not the assumed 110/95 g, so the body closes at **4.304 kg**, 6.3 % past the previous 4.05 kg. ~~Every design gate still passes (trot at 80 % of motor peak, cable SF 4.70, bearing C0 1277/1500 N)~~ — ⚠️ **the motor gate is gone, by [ADR-0100](DESIGN_DECISIONS.md) (M107).** ✅ **M111 (ADR-0104): 1.825 N·m peak / 0.646 continuous, INSIDE the proxy, at the 36/34/22 arms and a 4.468 kg body** — ⚠️ but the walked trot needs **~665 rpm** no-load against the proxy's 380, and has never fitted it at any arms. ✅ **M119 ([ADR-0110](DESIGN_DECISIONS.md)): bought by the WINDING** — the same 3505 frame at 9:1, rewound to `Kv_out ≥ 665 rpm / V_floor` (23.8 rpm/V, ×1.5, on 8S), keeps envelope, mass and thermal; a lower ratio cannot hold 0.624 N·m continuous. Before: with capstan friction counted the trot needs **2.42 N·m against the proxy's 1.95** — ⚠️ **2.42, not the 2.20 ADR-0100 published: that was the HIND leg, and [ADR-0102](DESIGN_DECISIONS.md) found the budget has only ever seen one leg.** The fore knee sets it, at 24 % over where the hind is 13, and the two overruns differ in kind — the hind's is routing and routes away, the fore's is load and does not, so the mechanism is the primary design and the motor's torque became an OUTPUT rather than a limit. The gates that remain are set by parts actually chosen: cable SF 4.70 and bearing C0 1277/1500 N, both holding. ⚠️ The proxy still supplies the Ø34.5 × 36.1 mm envelope and 131.7 g this row is built on, and whether a part meeting the spec keeps them is `[owed]`. History: 3.0 kg → **4.05** (ADR-0010, real 132 g motor) → **4.31** (ADR-0043, real joint hardware). A domestic cat is 4–5 kg. ~~⚠️ Not yet folded into `params.py`~~ — ✅ **that WAS the state before M41 and this cell kept saying it after**; ADR-0046 folded 4.3041 kg into `params.py` and re-derived NFR6 and NFR18 from it. M45 found the contradiction sitting inside this one cell. ⚠️ **And a FOURTH increase is now projected: 4.83 kg**, because [ADR-0050](DESIGN_DECISIONS.md) (M45) adopts ADR-0002 **Option A** at the ankle — four more motors at 132 g, **+528 g (+12.3 %)**, actuators 19 → 23. Not folded in yet: the CAD, the mass closure and `params` all still say 4.3041, and the compiled MuJoCo plant does not show it either (the motors live in `trunk_mass`). |
| NFR6  | Runtime on one battery charge | ✅ **17.9–23.8 min / ~714 m — M126**. ✅ 17.8–23.7 min / ~711 m — M124 ([ADR-0115](DESIGN_DECISIONS.md))**. ✅ 17.8–23.6 min / ~709 m — M123 ([ADR-0114](DESIGN_DECISIONS.md))**: the hollow hip's +104 g of body. ✅ 18.2–24.2 min / ~725 m — M122 ([ADR-0112](DESIGN_DECISIONS.md))**: friction is charged where the cable slides (its Bowden conduit), not on every degree of wrap. ✅ **15.6–21.1 min / ~634 m — still MET after M120 ([ADR-0111](DESIGN_DECISIONS.md)) carries G3's 85.6 g.** ~~16.0–21.7 min / ~650 m~~ — MET at both Kt corners, by [ADR-0104](DESIGN_DECISIONS.md) (M111).** The 36/34/22 moment arms ADR-0103 adopted for the fore leg are a reduction: the same joint torque at 1/r the cable tension, and copper goes as its square, so it halves. Efficiency 16.5 → 30.7 %. ~~⚠️ **8.8–12.7 min / ~381 m — BELOW its own re-stated range, by [ADR-0100](DESIGN_DECISIONS.md) (M107), corrected by ADR-0101.** ✅ **And routing recovers some of it:** the hip spool wants z ≈ −20 where it sits at +37, which takes the trot peak 2.20 → 1.93 N·m and puts the motor requirement back inside the proxy. Whether the girdle can house it 16.6 mm below its row's lower slot is `[owed]`. Capstan friction had never reached the plant: ADR-0003 specified the model, `tendon.py` implemented it, `wrap_angle` was 0.0, and ADR-0083 solved every wrap in M78 into a `pair_wrap` that nothing read. Counted, it costs **71 %** of the trot's copper — runtime **18.81 → 12.13 min** optimistic and **13.58 → 8.50** pessimistic, range **565 → 364 m**. Both Kt corners now fall under the 14–20 min below, where before only the pessimistic one was marginal. ⚠️ And the Kt question hardened: RMS current is 1.380 A at Kt 0.44 and **1.735 A** at 0.35 against a **1.60 A** continuous rating, so it now decides whether the motor runs cool, not just how long. ~~⚠️ **14–20 min / 420–600 m**~~ trotting at 50 cm/s — **re-stated by ADR-0044 (M39)** from the published ~30 min / ~900 m. **Three corrections and one uncertainty.** Corrections: ADR-0043's 4.304 kg body and the 8.75 mm spool §2 requires (−17 %, → 25.2 min at 100.2 W), and `power.py`'s copper-loss formula, which uses `I²R_pp` where balanced three-phase is `3I²R_ph = 1.5×` that (→ 19.6 min at 128.6 W; its own docstring flagged it and nothing had priced it). Uncertainty: the vendor's Kt disagrees with its own current ratings by 27 %, worth the rest of the spread (→ 14.1 min at 178.2 W). ⚠️ Rotor-side is **ruled out** as the explanation (7.1× off, wrong direction); a six-step-vs-sinusoidal convention fits to 0.4 %, in which case both vendor numbers are right and only the driver's current sense decides. Standing with the ADR-0003 brake scales the same way. 300 g pack, `[assumed]` 175 Wh/kg / 80 % usable. |
| NFR17 | **Power-off stance brake** | ⚠️ **Re-priced by [ADR-0108](DESIGN_DECISIONS.md) (M115): still worth having, no longer "required, not optional" on this argument.** At the stance actually held, standing costs **31 %** of trotting, not 76 %, and the brake multiplies standing endurance **3.1×** (54 → 168 min), not 4.5×. The 76 % came from pricing the stand at the worst reachable pose on every joint at once. ~~Required, not optional — standing costs 76 % of moving for zero work; the brake is worth 4.5× standing endurance (ADR-0021).~~ |
| NFR18 | **Girdle surface finish + duty limit** | ⚠️ **M126: anodised continuous trot 93.1 °C.** ⚠️ M124: 93.4 °C. ⚠️ **M123 ([ADR-0114](DESIGN_DECISIONS.md)): anodised continuous trot 91.6 → 93.6 °C**; forced air h ≈ 15 → 70.9 °C, one battery 67.9 °C. ⚠️ M122 ([ADR-0112](DESIGN_DECISIONS.md)): anodised continuous trot 102.8 → 91.6 °C** — still over 80 °C, so forced air is still required; at h ≈ 15 it settles at 69.4 °C. Girdles **anodised** (ε ≥ 0.9) — worth **~59 K** (⚠️ re-derived by ADR-0045; the lever grew because radiation goes as T⁴ and the operating point rose). **Continuous/tethered trotting is OUT OF SPEC in still air at ANY finish** — anodised settles at **96.1 °C** (~~74.9~~). ⚠️ **And the battery-limited case is now marginal, not comfortable: 70.2 °C** against the 70 °C line it used to clear by 10 K. ⚠️ **Forced air is REQUIRED for continuous operation, not an option**: h ≈ 15 brings it to 72.7 °C, h ≈ 25 to 58.2 °C. Winding runs **+11.5 K** above skin (~~+7.7~~), so anodised continuous winding is **107.6 °C** and polished **166.7 °C** — the magnet-range concern is sharper (ADR-0024/0045). |
| NFR7  | Max cable tension per tendon | ❓ TBD (N) |

## 4. Constraints & assumptions

- Antagonistic tendon pairs are needed because a cable can only pull. Settled by
  [ADR-0008](DESIGN_DECISIONS.md): **one motor per DOF**, driving both sides of
  the pair through a **variable-radius pulley** — the mass budget does not permit
  two motors per DOF.
- Cables are inextensible enough that motor rotation maps predictably to joint
  angle, but tendon stretch and friction must be modeled/compensated.
- Motors, drivers, battery, and main compute live in the torso.

## 5. Open questions

> **Prioritised by consequence in [OPEN_RISKS.md](OPEN_RISKS.md)** — which of the
> 48 `[owed]` / 89 `[assumed]` items can actually change a decision, and what
> closes each. Two dominate: **motor mass** (21 % margin before the budget breaks)
> and **paw friction** (met with none).

The major architecture questions are **resolved** in the [ADR log](DESIGN_DECISIONS.md):
- Actuator choice → tendon-drive, BLDC + FOC (ADR-0003).
- Tension sensing → hybrid: motor-current estimate everywhere + joint-end load
  cells on stiffness-critical joints (ADR-0004).
- Compute split → distributed CAN-FD drivers + RT controller + SBC (ADR-0005).
- Tendons per DOF → antagonistic pairs; spring-return for distal joints (ADR-0002).

Remaining **calibration / measurement** items (not decisions):
- ❓ Routed cable friction μ and per-tendon wrap — blocks the tension error budget
  and the current-vs-load-cell placement split (ADR-0004 follow-up).
- ✅ **Specific motor part — CLOSED** by the
  [reality check](notes/motor-reality-check.md): **SteadyWin GIM3505-9**, 0.71 /
  1.95 N·m at the output, 9:1, **131.7 g with driver**, 24 V, Kt 0.35 N·m/A. The
  ≤80 g class target does not exist in this torque band; NFR5 rose to 4.05 kg as
  a result (ADR-0010). ⚠️ Still owed: buy and weigh one, and a **thermal test** —
  sustained trot is a 2.1× overload on the continuous rating.
- ❓ Per-tendon force target (NFR7). *(Runtime/NFR6 closed by ADR-0021.)*

## 6. Out of scope (for now)

- Autonomous navigation / SLAM.
- Manipulation (the cat does not need to pick things up).
- Outdoor / all-terrain operation.

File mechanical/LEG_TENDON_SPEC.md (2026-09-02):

# TomCat — Leg Tendon-Drive Mechanical Spec (first pass)

Owner: **tomcat-mechanical** · Milestone: **M1** · Ties to
[ADR-0002](../docs/DESIGN_DECISIONS.md), [ADR-0003](../docs/DESIGN_DECISIONS.md),
[ADR-0004](../docs/DESIGN_DECISIONS.md).
Status: **first-pass** — every value is a placeholder unless labelled `[sourced]`.

ADR-0003 committed the project to **pure tendon-driven legs** (honoring P1),
*knowingly* accepting a high cable-tension burden that the leg-actuator trade
study ([leg-actuator-tradeoff.md](../docs/notes/leg-actuator-tradeoff.md)) scored
against. This document is the mechanical answer to that burden: it engineers the
tension down to a buildable number and specs the cable, pulleys, bearings,
routing, and static-hold hardware that follow. It presents numbers as tables for
**tomcat-kinematics** / the lead to fold into `LegParams` / `TendonParams` later.
It does **not** edit `params.py`, `kinematics/`, or `docs/`.

Conventions match the kinematics model and
[SPINE_TAIL_SPEC.md](SPINE_TAIL_SPEC.md): **SI units**; sagittal-plane
**digitigrade 4-link leg** (hip → femur → stifle → tibia → hock → metatarsus →
*passive* paw) with **3 actuated joints**; joint torque `τ = T·r`, so cable
tension `T = τ / r` (+ a pretension / co-contraction floor).

Label legend: `[sourced]` traceable to lit-review / ADR / M1 budget;
`[assumed]` first-pass engineering guess; `[owed]` must come from another owner.

---

## 0. The tension problem, stated

`T = τ / r`. A **small moment arm hugely amplifies required cable tension** —
this is the entire burden ADR-0003 accepted. The worst case (single-leg
**land**, 73.6 N foot force × 2.5 impact) drives **~12.4 N·m at the hip**. At
the original placeholder arms (hip 15 mm, knee 12 mm) this yielded **~870 N
(hip) / ~1050 N (knee)** — **15–50× the RoboCat ~20–70 N sanity band**
`[sourced: M1 budget; lit Q6]`.

Two things must be said honestly up front:

1. **Geometry alone roughly halves the peak, no more.** The largest pulley a
   cat-scale leg joint can package is ~25–28 mm; that cuts the land peak from
   ~1050 N to ~450 N (§1). It **cannot** reach the RoboCat 20–70 N band, because
   that band is a lighter, non-impact demonstrator — our peak is a deliberate
   ×2.5 single-leg *landing transient*, not a continuous load.
2. **The residual is a transient, not a duty.** Under **stand and trot** the same
   arms give 50–150 N cable tension — near the RoboCat band. The irreducible
   ~450 N lives **only** in the rare land impact, and it sets **structural**
   sizing (cable break strength, pulley/bearing static rating), not continuous
   thermal/fatigue sizing. That distinction is what makes the design buildable.

---

## 1. Moment-arm sizing per leg joint

### 1.1 Joint torques by load case

Torque scales linearly with foot support force. All three columns are now taken
directly from the **post-M4 whole-body budget** in the digitigrade posture
`[sourced: whole_body_budget]` (trot scaled from the same sweep at 22.08 N).

> ⚠️ **STALE — corrected by M36 ([ADR-0041](../docs/DESIGN_DECISIONS.md)).** This
> table is the **pre-ADR-0010** budget, computed at the 3.0 kg body. The live
> `torque_budget.evaluate` at the shipped 4.045 kg returns **hip 16.67 / stifle
> 10.23 / hock 6.46 N·m** — every entry low by the mass ratio 4.045/3.0 = **1.35**.
> §2 *was* re-run (it says "~600 N at the hip land transient", which is exactly
> 16.67 / 0.028) so this document has contradicted itself since ADR-0010.
> **§1.3, §1.3a, §3.5 and ASSEMBLY_SPEC §0.1 are all derived from the numbers
> below and inherit the error.** Gated by `tests/test_leg_detail.py`.

| Joint | Stand (4-leg, ×1.0) | Trot (2-leg, ×1.5) | **Land (1-leg, ×2.5)** | Source |
|---|---|---|---|---|
| **Hip** | 1.24 N·m | 3.71 N·m | **12.36 N·m** ← worst | `[sourced: budget]` |
| Stifle (knee) | 0.75 N·m | 2.25 N·m | **7.49 N·m** | `[sourced: budget]` |
| Hock (ankle) | 0.48 N·m | 1.44 N·m | **4.79 N·m** | `[sourced: budget]` |

The digitigrade fold **redistributed** these versus the old flat-footed posture:
the stifle dropped sharply (12.6 → 7.49 N·m) while the hock rose (3.68 → 4.79),
because the folded metatarsus now carries more of the landing moment. ADR-0002
still reserves the hock as spring-return (Option B), so its tendon *count* is
lightest — but not its *force*.

### 1.2 Packageable arm at each joint

The lever is bounded by where the pulley physically fits, and by the P1 cost of
distal mass: a big pulley at the **knee/ankle** adds swing inertia and erodes the
very limb-inertia win that motivated tendon-drive (trade study Axis 3). So the
arm is pushed largest where it is cheapest (hip, at the body pivot) and held to
the smallest defensible value distally.

| Joint | Placeholder r | **Recommended r** | Upper bound set by | P1 cost | Label |
|---|---|---|---|---|---|
| Hip | 0.015 m | **0.028 m** | girdle/hip housing has room; motor at pivot | ~none (r≈0 from swing axis) | `[assumed]` |
| Knee  | 0.012 m | **0.025 m** | mid-limb pulley vs. shank clearance & ROM | moderate (adds distal mass) | `[assumed]` |
| Ankle | 0.010 m | **0.014 m** | distal, tight; spring-return joint | high (worst place for mass) | `[assumed]` |

Trade-study guidance was "knee arm **≥ ~25 mm** to cap tension near ~500 N"
`[sourced: leg-actuator-tradeoff §4]` — the 25 mm recommendation meets that
exactly.

> ⚠️ **M36 closed the other half of this trade, and it closes shut.** Turned as
> real parts the three sheaves are **41 g of a 110 g leg** — §1.3a priced only the
> ankle's *inertia*, from a 6 g-at-14 mm estimate scaling as `r²`, and never priced
> the set's mass. So there is now a reason to want the arms **smaller**, and there
> is no room: at the shipped arms the **trot** case already sits at **81 %** of the
> GIM3505-9's 1.95 N·m peak (agreeing with §2's own "0.82× peak"), and 0.85× the
> arms puts it **over 100 %**. The arms are pinned by the actuator.
>
> | arm scale | sheave set | T land | T trot | trot / motor peak |
> |---|---|---|---|---|
> | **1.00** (shipped) | **41.3 g** | 615 N | 198 N | **81 %** |
> | 0.85 | 32.9 g | 720 N | 230 N | **101 %** ❌ |
> | 0.70 | 25.4 g | 870 N | 275 N | 133 % ❌ |

### 1.3 Resulting cable tension (T = τ/r + pretension)

Pretension floor 5 N (matches current `TendonParams`); the AIC co-contraction
bias `T_bias` (Kengoro ≈ 19.6 N, applied at runtime) would add a few % more.

> ⚠️ **Recomputed after the M4 posture fix.** The figures below are from the
> current model (digitigrade negative-knee fold, stance `(0.05, −0.19)`, real
> distributed mass). The *earlier* revision of this table was computed under the
> old positive-knee posture with feet ~0.2 m ahead of the hips — a posture since
> shown to be statically unstable. **The worst joint changed: it is now the HIP,
> not the knee, and the ankle load rose sharply.**

| Joint | r | Stand | **Land (peak)** | Old-posture land peak | Change |
|---|---|---|---|---|---|
| **Hip** | 0.028 m | 49 N | **~447 N** ← worst | ~470 N | −5 % |
| Knee (stifle) | 0.025 m | 35 N | **~305 N** | ~510 N | **−40 %** |
| **Ankle (hock)** | 0.014 m | 39 N | **~347 N** | ~270 N | **+29 %** ⚠ |

Driving joint torques (single-leg land, ×2.5): hip **12.36 N·m**, stifle
7.49 N·m, hock 4.79 N·m.

**What geometry solved / what remains:**
- **Solved:** continuous operation (stand) now sits at **35–49 N** — inside the
  RoboCat ~20–70 N band, an ordinary cable-drive regime.
- **Irreducibly remains:** a **~450 N hip land transient.** No packageable arm
  removes it. This residual is the *structural design load* for
  cable/pulley/bearing (§2, §3) — a rare peak, not a duty.
- **Hock arm — reviewed, KEEP 14 mm.** See §1.3a below.

**Recommended moment-arm set → `TendonParams.joint_moment_arm = (0.028, 0.025,
0.014) m`** *(hock confirmed by §1.3a)*. Structural design load is now
**~465 N per tendon** (hip land + `T_bias`), down from ~525 N under the old
posture. **Hardware sizing in §2–§3 is deliberately RETAINED at the 525 N
basis** — an 11 % load drop is not a reason to downsize a structural margin,
and the placeholder inputs could still move. Components remain sized to
**~1 kN**.

### 1.3a Hock moment-arm review — **verdict: keep 14 mm**

M4's posture change raised the hock land peak 29 % (270 → 347 N) on the leg's
smallest arm, so the arm was reviewed. Because M4 also added real mass
properties, the P1 inertia cost could be *priced* rather than asserted. Leg
swing inertia is taken about the hip in the stance pose (per-link point masses at
their CoMs); the hock sits **134 mm** out on a 280 mm leg, so mass added there is
expensive. Pulley+bracket mass is estimated at 6 g at 14 mm scaling as `r²`
`[assumed]`.

| r (mm) | Land T (N) | Stand T (N) | added mass (g) | leg swing-inertia penalty |
|---|---|---|---|---|
| **14 (current)** | **347** | **39** | 6.0 | **5.1 %** |
| 18 | 271 | 32 | 9.9 | 8.4 % |
| 20 | 245 | 29 | 12.2 | 10.3 % |
| 25 | 197 | 24 | 19.1 | 16.1 % |

**Keep 14 mm.** Growing the arm buys nothing the design needs, and costs the one
thing tendon-drive exists to protect:

1. **Continuous load is already in band.** Stand tension is **39 N** at 14 mm —
   inside the RoboCat 20–70 N band. The 347 N is a *rare landing transient*.
2. **The transient is already covered.** With `T_bias`, the hock peaks at 367 N →
   **SF 6.0** on the specified 2.2 kN cable, comfortably past the SF ≥ 4 target,
   and only **37 %** of the ~1 kN hardware rating. It is *not* the governing
   tendon — the **hip** is, at 467 N / SF 4.7.
3. **It would attack P1.** Going to 25 mm adds **+11 percentage points** of leg
   swing inertia. Low limb inertia is the entire reason ADR-0003 accepted the
   tendon-drive tension burden ([trade study](../docs/notes/leg-actuator-tradeoff.md)
   Axis 3) — spending it to relieve a transient already carrying SF 6 is a bad trade.

**Revisit if** the impact factor rises above ×2.5, the body mass grows, or a
measured pulley mass comes in far below the `r²` estimate.

### 1.4 Cable-travel / spool sanity check

> ⚠️ **UNDERSTATED for the knee and ankle — M37 ([ADR-0042](../docs/DESIGN_DECISIONS.md)).**
> The table below computes `r x ROM` **per joint**, which assumes the tendon map is
> diagonal. It is not: a via-pulley concentric with a proximal axis couples the
> joints by its own radius per radian (8.75 mm, the cable's minimum bend). Real
> worst-case travels are **117 / 102 / 104 mm**, not 117 / 65 / 44 — the knee
> understated 56 %, the ankle 135 %. The hip remains the sizing case, but the three
> spools are one class rather than 2.7x apart.

At `motor_spool_radius = 0.008 m`, using the **post-M4 negative-fold limits**
(hip ±120°, stifle −150…0°, hock −30…+150°):

| Joint | ROM | travel = r·ROM | motor sweep |
|---|---|---|---|
| Hip | 240° = 4.19 rad | `0.028 × 4.19 =` **117 mm** | 14.6 rad ≈ **2.3 rev** |
| Stifle | 150° = 2.62 rad | `0.025 × 2.62 =` **65 mm** | 8.2 rad ≈ 1.3 rev |
| Hock | 180° = 3.14 rad | `0.014 × 3.14 =` **44 mm** | 5.5 rad ≈ 0.9 rev |

⚠ The widened hip range pushes hip cable travel to **117 mm / ~2.3 rev** (was
88 mm at the old ±90°). Still fine for a multi-wrap spool, but it is now the
sizing case — check spool width and wrap stacking against it.

---

## 2. Cable spec

Structural design tension **~600 N** at the hip land transient (ADR-0010, at the
revised 4.05 kg body; was ~465 N at 3.0 kg); target **safety factor ≥ 4** on peak
(covers knot/splice strength loss ~30–50 %, abrasion, and fatigue) →
**breaking strength ≥ ~2.4 kN**, met with margin by the 1.75 mm cable below.

**Recommendation: ~~1.5 mm~~ → 1.75 mm braided UHMWPE (Dyneema SK78 / SK99,
12-strand).**

> ⚠️ **Re-sized by ADR-0010.** When NFR5 rose 3.0 → 4.05 kg (the real motor is
> 132 g, not the 72 g class target — [reality check](../docs/notes/motor-reality-check.md)),
> every tendon load scaled with it. The hip land transient went **465 → 600 N**,
> which drops 1.5 mm cable to **SF 3.67 — below this section's own ≥ 4 target**.
>
> | Cable | Break `[derived: area-scaled from the 1.5 mm figure]` | SF at 600 N | Min bend r (10×D) | Trot hip motor torque |
> |---|---|---|---|---|
> | 1.5 mm | ~2.2 kN | **3.67** ❌ | 7.5 mm | 1.47 N·m (0.75× peak) |
> | **1.75 mm** | ~3.0 kN | **4.99** ✅ | 8.8 mm | 1.61 N·m (0.82× peak) |
> | 2.0 mm | ~3.9 kN | 6.52 | 10.0 mm | 1.84 N·m (0.94× peak) |
>
> **1.75 mm is the pick.** 2.0 mm would be safer on the cable but its larger bend
> radius forces a bigger spool, and `τ_motor = T · r_spool` then pushes the trot
> case to 0.94× the real motor's peak — trading a cable margin for an actuator
> margin that is tighter. The spool radius must rise **8.0 → 8.75 mm** to suit.
>
> `[owed]` The break strengths above are **area-scaled**, not read off a product
> table. Confirm against a real SK78/SK99 datasheet before committing.

| Property | Value | Note / source |
|---|---|---|
| Material | UHMWPE (Dyneema SK78/SK99) | `[sourced]` high-modulus, creep-optimized grades |
| Diameter | **1.5 mm** | `[assumed]` sized to break strength + min bend radius |
| Breaking strength | **~2.2–2.5 kN** | `[sourced]` typical 1.5 mm 12-strand; SF ≈ 4.3–4.8 on 525 N |
| Tensile modulus (fibre) | ~100–120 GPa (SK99) | `[sourced]` — settled/spliced effective ~50–90 GPa |
| Elastic stretch at break | ~3–4 % | `[sourced]` low elastic stretch → good position fidelity |
| **Creep** | **non-negligible under sustained load** | `[sourced]` — the key drawback (see below) |
| Min sheave dia | ≥ ~10× cable dia → ≥ 15 mm | `[sourced]` UHMWPE bends tight; all joint pulleys (Ø50–56 mm) pass easily |
| Density | ~0.97 g/cm³ (floats) | `[sourced]` very light → protects P1 limb-inertia budget |

**Why not steel:** 1.0–1.2 mm 7×19 stainless wire rope reaches ~1.0–1.3 kN break
(marginal SF), has **near-zero creep** and high stiffness — but it needs a
**much larger min bend radius** (sheave dia ≥ ~15–20× rope dia → ≥ ~20 mm even
for idlers), suffers **bending fatigue** over small distal pulleys, and is
~8× denser (hurts P1 distal inertia). For compact multi-pulley routing to distal
joints, **UHMWPE wins**; steel is the fallback only if creep drift proves
unmanageable and larger pulleys are accepted.

**Creep / stretch handling (position-accuracy consequence):** UHMWPE elastic
stretch is low, but it **creeps** slowly under sustained tension — exactly the
stance-hold regime. This introduces slow position drift that a pure motor-side
encoder cannot see. Mitigations, in order:
1. **Static-hold brake (§4)** removes sustained tension from the cable during
   quiet stance — the single biggest creep reducer.
2. **Heat-set / pre-stretched** cable at build (settles construction stretch and
   much of primary creep).
3. **Cable/joint-state sensor** (ADR-0004, kept distinct from the rotor encoder)
   for periodic re-tension / recalibration — creep is slow, so low-rate
   correction suffices.

**Axial cable stiffness** (for a tendon-stretch term in the tendon map):
`k = E·A / L`. For 1.5 mm (A = 1.77 mm²), settled E ≈ 60 GPa, run L ≈ 0.30 m
(girdle → distal joint): `k ≈ 60e9 × 1.77e-6 / 0.30 ≈ 3.5×10⁵ N/m`. Stiffness is
**per-tendon and run-length dependent** — kinematics should compute it from the
per-tendon path length, not a single constant. Placeholder: `cable_stiffness ≈
3.5e5 N/m` `[assumed]`.

---

## 3. Pulley / bearing / routing (design load ~1 kN)

### 3.1 Joint pulleys

- **Sheave diameters** follow §1.2 arms: hip Ø56 mm, knee Ø50 mm, ankle Ø28 mm
  (radius = moment arm; the cable pitch line sits at `r`). All comfortably exceed
  the ≥15 mm UHMWPE min-bend.
- **Groove:** round-bottom, radius ~0.55× cable dia — **≈0.96 mm for the
  Ø1.75 mm cable §2 actually specifies.** ⚠️ The ~~0.85 mm / 1.5 mm~~ figure here
  predates ADR-0010's cable re-size and would pinch the specified cable (M36).
  The *rule* is what holds, not the literal; anodized aluminum or hard-anodized with a smooth groove to
  keep μ low.
- **Structural:** aluminum sheave for the ~1 kN transient; a steel bushing/insert
  at high-load hip/knee if wear shows.

### 3.2 Bearings — split the sizing by load type

The resultant radial load on a pulley bearing is the vector sum of the two cable
segments, up to **~2·T** for a 180° wrap → **~1.0 kN** at the knee land peak.

| Rating | Sized to | Value | Rationale |
|---|---|---|---|
| **Static C₀** | land transient resultant | **≥ ~1.5 kN** (SF 1.5 on ~1 kN) | rare peak; brinelling is the failure mode |
| **Dynamic C** | continuous trot resultant | **≥ ~0.3 kN** (2 × ~150 N) | fatigue life is set by continuous gait, not the rare land |

This split is the key to keeping bearings small: sizing dynamic (fatigue) rating
to the **land** peak would force needlessly large bearings, but the land is a
transient. Candidate: miniature deep-groove ball bearings (e.g. 3–5 mm bore, 623/
MR series at distal joints; a larger 6 mm-bore 626-class at hip/knee where C₀ is
easiest to hit). Exact PNs `[owed: BOM pass]`.

### 3.3 Routing paths (girdle motors → joints)

Centralized-motor / P1: all leg motors live in the shoulder & pelvic **girdles**.
Each joint tendon runs from its girdle spool, over redirect/idler pulleys, to the
joint sheave, then to its anchor. Antagonistic pairs (ADR-0002) for hip and knee;
ankle is single-tendon + return spring (Option B).

| Tendon | Path | Approx run length | Routing | Label |
|---|---|---|---|---|
| Hip (agonist/antag.) | girdle spool → hip sheave → anchor | ~0.10 m | **open pulleys** | `[assumed]` |
| Knee (agonist/antag.) | girdle spool → hip idler (via-point) → knee sheave → anchor | ~0.22 m | **open pulleys** | `[assumed]` |
| Ankle (single + spring) | girdle spool → hip idler → knee idler → ankle sheave → anchor | ~0.30 m | open pulleys; short **sheath** only where it crosses the shank | `[assumed]` |

**Open pulleys vs. sheath (Bowden):** prefer **open low-friction idler pulleys**
throughout — sheaths add large distributed capstan friction (μ high over long
wrap). Use a short PTFE-lined sheath **only** where a cable must bend around
structure with no room for a pulley (e.g. crossing the moving shank). This mirrors
Kengoro's low-friction guide approach `[sourced: lit Q6]`.

### 3.4 Wrap angles (for capstan-friction modeling)

Capstan: `T_out = T_in · e^(μ·θ)`, θ = total wrap in radians. Kinematics needs
per-pulley wrap to model the tension the **motor** must supply vs. what the
**joint** receives.

| Pulley station | Wrap angle θ | Note | Label |
|---|---|---|---|
| Motor spool | ~180° (π) | 0.5–1 wrap on the spool | `[assumed]` |
| Hip sheave (hip tendon) | up to ~240° | = hip ROM (±120°) + anchor seat | `[assumed]` |
| Hip idler (knee/ankle pass-through) | ~30–45° | redirect only | `[assumed]` |
| Stifle sheave (knee tendon) | up to ~150° | stifle ROM (−150…0°) | `[assumed]` |
| Knee idler (ankle pass-through) | ~30–45° | redirect only | `[assumed]` |
| Ankle sheave | ~60–90° | `[assumed]` |

> ⚠️ ~~**OVER-estimated — M37 ([ADR-0042](../docs/DESIGN_DECISIONS.md)).** Solved
> rather than assumed, the wrap angles are much smaller than tabulated here: the
> ankle path sums to **~108°**, not 360°, so its capstan penalty is **~1.21x**, not
> 1.87x. Good news — the motor-side tension margin this was inflating can come back.
> Wraps are computed by `cad/tendon_route.py` from the real station geometry.~~
>
> > ⚠️ **THAT IS THE FLEXOR ONLY — [ADR-0083](../docs/DESIGN_DECISIONS.md)
> > (M78).** `route(side=-1)`, the **extensor** of the same antagonistic pair,
> > had never been called. It solves to **392.9° / 1.985x** — essentially the
> > 1.87x this banner called an over-estimate. The margin came back on one cable
> > of two, and the cause is this spec's own §3.4 budget being blown: **198° on
> > the hip via** (a redirect, budgeted 30–45°), and 140° on the same via from
> > the knee flexor.

**Friction coefficient:** UHMWPE over anodized-aluminum pulley, lightly
lubricated: **μ ≈ 0.08–0.12**; over a PTFE-lined sheath μ ≈ 0.05–0.10 but with
much larger effective wrap. Placeholder `friction_coeff = 0.10` `[assumed]`.

**Capstan penalty example (ankle tendon, the worst path):** summed wrap ≈ 180 +
45 + 45 + 90 = 360° = 6.28 rad; at μ = 0.10, `e^(0.10×6.28) = 1.87` → the motor
must pull **~87 % more** tension than the joint receives, and on release the
joint sees correspondingly less. This quantifies why routing must **minimize
wrap and use open pulleys**: friction directly inflates the motor-side tension
(and the cable break-strength margin) it takes to deliver a given joint torque.

---

### 3.5 Link (bone) structural sizing — closes review F3

The specs sized the cable, pulleys and bearings but never **the links
themselves**. A link must transmit its joint's torque, so it carries a bending
moment equal to that torque.

**Key identity — the moment arm does NOT affect this.** It is tempting to say a
big pulley "levers" the bone harder, but `M = T·r` and `T = τ/r`, so
`M = (τ/r)·r = τ` **identically**. The link's bending moment is just the joint
torque, set by the ground reaction and leg geometry. Growing `r` cuts *cable
tension* and leaves *link stress untouched* — the two design levers are
independent, and there is no trade between them. (An earlier revision of the
design review claimed such a trade; that was an error.)

Bending stress `σ = M / Z`, tube `Z = I/r_o`. Allowable **σ ≈ 400 MPa** for a
CF tube in bending `[assumed — conservative; confirm against a real tube
datasheet, and check local wall crushing/buckling, not just material strength]`.

At the original uniform **8 × 1 mm** tube the femur reached **364 MPa → SF ≈ 1.1**
— effectively no margin on the landing transient. Adopt a **graded set, thickest
proximally**, which equalises the safety factor and keeps added mass off the
distal links (P1):

> ⚠️ **SUPERSEDED by M36 ([ADR-0041](../docs/DESIGN_DECISIONS.md)).** The table
> below uses §1.1's stale torques *and* omits the torsion the joint sheave's real
> lateral offset imposes. Re-derived from the live budget at the offsets the 3D
> layout produces (12.2 / 12.2 / 9.2 mm), the same sections give
> **SF 1.97 / 2.08 / 1.84** — the femur and metatarsus fall below the SF 2 floor
> that ASSEMBLY_SPEC §0.1's argument rested on.
>
> **Remedy, and it is nearly free:** one step up in stock tube each. Bending
> strength goes as the *cube* of diameter while tube mass goes as the first power,
> so **Ø12→Ø14, Ø10→Ø12, Ø8→Ø10** restores **SF 2.78 / 3.16 / 3.11** for **under
> 4 g on the whole leg**. Computed by `size_tubes()` in
> `cad/tomcat_leg_detail.py`, gated by `tests/test_leg_detail.py`.

| Link | Torque | **Section** | Z (mm³) | σ (MPa) | **SF** | mass |
|---|---|---|---|---|---|---|
| Femur | 12.36 N·m | **Ø12 × 1.0** | 87.8 | 141 | **2.84** | 4.8 g |
| Tibia | 7.49 N·m | **Ø10 × 1.0** | 58.0 | 129 | **3.10** | 4.2 g |
| Metatarsus | 4.79 N·m | **Ø8 × 1.0** | 34.4 | 139 | **2.87** | 2.4 g |
| Paw (passive) | — | Ø8 × 1.0 | — | — | — | 0.9 g |

**Cost: +2.7 g per leg** (9.5 → 12.2 g of bone) and **+0.9 % leg swing inertia** —
negligible, because the added material sits proximally where the inertia lever is
short. Buckling is not the failure mode (tibia Euler `P_cr ≈ 10.5 kN`, SF ≈ 34).

> Remaining check `[owed]`: joints see combined bending **and torsion**, and the
> tube must also survive the local contact/crushing load where a pulley or clevis
> clamps it. Both need a real section and joint detail (F5).

## 4. Static-hold offload

The [sensorless-FOC note](../docs/notes/sensorless-foc-stance-hold.md) establishes
that a quasi-static high-torque hold is a **thermally-limited DC operating point**
(I²R in one/two phases, no rotation to share heat; continuous holding torque must
be derated well below peak). Holding stance electrically also keeps the creeping
cable (§2) under sustained tension. Both problems are removed by a mechanical
hold.

**Recommendation: a girdle-mounted, power-off (spring-engaged, electrically
released) friction brake on each leg motor shaft.**

- **Sizing:** holds spool torque = `T_hold × r_spool`. Quiet-stance hold tension
  is 50–160 N → `0.16 × 0.008 ≈ 1.3 N·m` at the spool worst case; a small PM
  brake covers it. (It need not hold the *land* peak — that is dynamic, when the
  brake is released and the motor is active.)
- **Location:** at the girdle motor, not the joint — keeps mass centralized (P1),
  off the distal limb.
- **Fail-safe:** spring-engaged means it holds stance **on power loss** — a
  perched cat does not collapse if power drops.

**Trade-off vs. backdrivability (the crux of ADR-0003):**

| Option | Backdrivable? | Static hold cost | Verdict |
|---|---|---|---|
| Electrical DC hold (no brake) | yes | high (thermal derate, cable creep) | baseline, thermally limited |
| **Power-off friction brake (recommended)** | **yes when released** | ~zero when engaged | engage only for true quasi-static postures |
| Non-backdrivable reduction (worm/lead-screw) | **no** | ~zero | **rejected** — kills IMF/agility, violates the ADR-0003 backdrivability intent |

The brake is strictly a **stance-only** device: **engaged** for standing/perching
(offloads thermal + creep), **released** for all locomotion and landing so the
leg keeps the full backdrivability and shock compliance ADR-0003 chose
tendon-drive to preserve. A non-backdrivable reduction would give the same hold
"for free" but permanently, defeating the purpose — hence rejected.

---

## 5. Parameter table → `LegParams` / `TendonParams`

For tomcat-kinematics / the lead to fold in. Field names match existing
dataclasses; proposed **new** fields are flagged.

### 5.1 `TendonParams` (existing fields)

| Field | Current | **Proposed** | Unit | Source label |
|---|---|---|---|---|
| `joint_moment_arm` | `(0.015, 0.012, 0.010)` | **`(0.028, 0.025, 0.014)`** | m | `[assumed]` — largest packageable; halves land peak (§1) |
| `motor_spool_radius` | `0.008` | `0.008` (unchanged) | m | `[assumed]` — travel/sweep check passes (§1.4) |
| `pretension` | `5.0` | `5.0` (keep as floor) | N | `[sourced: M1]` — AIC `T_bias` (~19.6 N) applied at runtime, not baked in |
| `spring_stiffness` | `(0.5,0.5,0.3)` | ankle only, `[owed]` | N·m/rad | ankle = Option-B return spring (ADR-0002); hip/knee antagonistic |
| `spring_rest_angle` | `(0.0,0.4,0.0)` | keep | rad | `[assumed]` |

### 5.2 Proposed **new** `TendonParams` fields

> ⚠️ **Still not folded in, ten milestones later — M37.** None of `cable_diameter`,
> `cable_break_strength` or `cable_stiffness` exists on `TendonParams`. And
> `motor_spool_radius` is still **0.008** where §2 requires **0.00875** for the
> Ø1.75 cable's minimum bend, so every motor angle and motor torque the model
> computes is **9 % out**. Gated by `tests/test_tendon_route.py`.
>
> ⚠️ **A field that is now known to be missing:** the map itself. `cable_lengths`
> is `delta = r * q`, diagonal; the routed hardware is lower-triangular with
> **±8.75 mm/rad** off-diagonals. See [ADR-0042](../docs/DESIGN_DECISIONS.md).

| Field (proposed) | Value | Unit | Source label |
|---|---|---|---|
| `cable_stiffness` | `3.5e5` (per-tendon; compute from run length) | N/m | `[assumed]` — `EA/L`, settled E≈60 GPa, 1.5 mm, ~0.30 m (§2) |
| `cable_diameter` | `0.0015` | m | `[assumed]` (§2) |
| `cable_break_strength` | `2200` | N | `[sourced]` 1.5 mm UHMWPE; SF≈4.3 on 525 N |
| `wrap_angle` | see §3.4 per station | rad | `[assumed]` — for capstan `T_out=T_in·e^(μθ)` |
| `friction_coeff` | `0.10` | — | `[assumed]` — UHMWPE / anodized-Al, open pulley (§3.4) |

### 5.3 `LegParams` (unchanged — geometry owned by kinematics)

| Field | Value | Unit | Note |
|---|---|---|---|
| `l1, l2, l3` | `0.120, 0.120, 0.050` | m | unchanged; moment arms above assume this scale |
| `q_min / q_max` | post-M4 negative fold: hip ±120°, stifle −150…0°, hock −30…+150° | rad | hip ROM now drives the 117 mm worst-case travel (§1.4) |

### 5.4 Derived design loads (for reference, not a param)

| Quantity | Value | Note |
|---|---|---|
| Peak cable tension (knee land + `T_bias`) | **~525 N** | structural design load per tendon |
| Component design load | **~1 kN** | margin over peak; also ≈ bearing resultant (2·T) |
| Continuous (trot) tension | 55–156 N | sets bearing fatigue (dynamic C) |

---

## Handoffs

- **→ tomcat-kinematics:** §5 tables. Headline changes: `joint_moment_arm`
  `(0.015,0.012,0.010) → (0.028,0.025,0.014)`; new `cable_stiffness`,
  `wrap_angle`, `friction_coeff`, `cable_*` fields for a tendon-stretch +
  capstan-friction term in the tendon map. `cable_stiffness` and `wrap_angle` are
  **per-tendon / per-path** — compute from each tendon's routed length and pulley
  list, not a single scalar.
- **→ tomcat-electronics:** each leg motor needs a **girdle-mounted power-off
  friction brake** (§4, ~1.3 N·m spool torque) plus its rotor encoder (ADR-0004);
  budget the brake driver channel + fail-safe wiring. Static hold is a
  thermally-derated continuous-torque point when the brake is *not* used.
- **→ tomcat-research:** the RoboCat 20–70 N band is a lighter, non-impact
  demonstrator; confirm whether a cat-scale ×2.5 single-leg land is the right
  worst case or over-conservative — it is the sole driver of the ~500 N residual.
- **→ lead:** the pure-tendon leg is buildable, but the ~500 N land transient is
  irreducible by geometry alone. If it proves to drive hardware mass/cost too
  hard, the trade-study hybrid (QDD-hip + tendon-knee ≥25 mm + spring-ankle)
  remains the documented fallback — a subsystem-level decision, not mine to make.

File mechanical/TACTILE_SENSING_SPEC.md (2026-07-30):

# TomCat — Tactile sensing & the paw structure

Owner: **tomcat-mechanical** / **tomcat-electronics** · Prerequisite for the
closed-loop balance milestone (M8).

Closed-loop balance is only as good as what it can sense, and for a legged robot
the decisive measurement is **at the contact**. This specifies what the paw must
measure, why the sensing the project already owns is not enough, and how the
sensor integrates into the paw structure without violating **P1**.

Every requirement below is **derived from the robot's own dynamics**
(`kinematics/src/tomcat_kin/dynamics.py`), not taken from a catalogue.

Label legend: `[derived]` computed from the model · `[sourced]` from literature
· `[assumed]` engineering guess · `[owed]` needs a part or a test.

---

## 1. What closed-loop balance actually needs

From the M6/M7 results, in priority order:

| # | Quantity | Why it is needed | Where from |
|---|---|---|---|
| 1 | **Contact ON/OFF per foot** | The gait's phase must sync to *reality*. M7's trot balance depends on the diagonal switching at the right instant; on real ground, touchdown time varies. | **paw — nothing else can do this** |
| 2 | **Normal force per foot** | Load sharing, and the contact-force distribution the ZMP/line-balance analysis assumes. | paw + joint torque |
| 3 | **Tangential/normal ratio** | Slip margin (**FR5**). M7 trot runs at μ ≈ 0.145 against a floor of 0.8–1.2, so margin is large — but slip must still be *detected*. | joint torque + paw |
| 4 | **Body attitude & rate** | The inverted-pendulum state (`line_balance`): the DCM needs CoM position *and* velocity. | IMU (ADR-0005) |

Items 1–3 are the paw's job. Item 4 is already covered.

## 2. Derived requirements

All from the shipped crawl (5.0 s) and trot (0.3 s) `[derived]`:

| Parameter | Value | Basis |
|---|---|---|
| Normal force, **measurement** range | **0–35 N** | peak per-foot normal is 30.9 N (crawl) / 30.3 N (trot) = 0.78 × body weight |
| Normal force, **survival** | **≥ 100 N** | the ×2.5 single-leg **land** transient (2.5 × 39.7 N body weight) — must survive, need not be accurate |
| Tangential range | **0–20 N** | 2.9 N at nominal trot; sized for μ→0.5 at full normal load |
| Resolution | **≤ 0.4 N** (~1 % FS) | to see unloading before liftoff, and slip onset |
| Bandwidth | **≥ 1 kHz** | trot stance is **150 ms**; 1 % timing resolution = 1.5 ms. Matches NFR3. |
| **Mass** | **≤ 20 g per paw** | see §4 — this is the binding constraint |
| Ingress | sealed | the pad is the ground interface |

⚠️ **Touchdown impact is not modelled** (ADR-0011). The swing profile lands the
foot at zero velocity relative to the ground in *both* axes, so the trajectory
itself implies no impact — but terrain error and tracking error will produce one.
The 100 N survival figure is the land transient, and is the best available proxy
`[owed: instrument a drop test]`.

## 3. Why the sensing we already own is not sufficient

The project is not starting from zero. [ADR-0004](../docs/DESIGN_DECISIONS.md)
already puts **load cells at the JOINT end** of the hip and stifle tendons
(joint-end specifically, so the capstan friction path does not corrupt them). A
**point contact exerts no moment**, so the foot force is only two unknowns and
`tau = J^T F` is solvable from two clean torque measurements.

So why add anything? Two reasons, one quantitative and one categorical.

**(a) The inversion is badly conditioned on the hind legs.**
`dynamics.grf_observability` reports the error amplification `[derived]`:

| Gait | Fore legs (median / worst) | **Hind legs (median / worst)** |
|---|---|---|
| Crawl | 3.4 / 3.5 | 5.2 / 6.1 |
| **Trot** | 3.2 / 3.4 | **7.5 / 36.3** |

The hind-leg estimate degrades ~10× **just before liftoff** — precisely when load
is transferring to the other diagonal and accurate load sharing matters most. A
1 % tension error becomes a 36 % force error there.

**(b) Joint torque cannot detect contact at all.** A torque signal cannot
distinguish "the foot is pressing on the ground" from "the limb is accelerating"
without a full dynamics model running in the loop. For **requirement 1** — the
one closed-loop balance most depends on — the joint route is not merely
imprecise, it is *categorically* unable. Only a sensor at the contact can say
*"we are touching now."*

## 4. The P1 constraint: distal mass is the real budget

A paw sensor sits at the **most distal** point of the limb, which is exactly what
tendon drive exists to keep light. M7 showed swing-leg torque is what caps trot
speed, so this trade can be measured rather than argued `[derived]`:

| Added per paw | Swing motor torque | Worst-motor RMS @ 96 cm/s | @ 120 cm/s | Top sustainable speed |
|---|---|---|---|---|
| 0 g | 0.112 N·m | 0.645 (0.91×) | 0.709 (1.00×) | **120 cm/s** |
| 5 g | 0.124 (+10 %) | 0.651 (0.92×) | 0.732 (1.03×) | 96 cm/s |
| 10 g | 0.135 (+20 %) | 0.661 (0.93×) | 0.755 (1.06×) | 96 cm/s |
| **20 g** | 0.158 (+41 %) | 0.690 (0.97×) | 0.803 (1.13×) | **96 cm/s** |
| 40 g | 0.204 (+81 %) | **0.749 (1.06×)** | 0.903 (1.27×) | **below 96 cm/s** ❌ |

**Rule: ≤ 20 g per paw.** Up to 20 g costs only the top 20 % of speed
(120 → 96 cm/s). At 40 g the RMS motor torque exceeds the continuous rating even
at 96 cm/s, so the sensor starts *taking away usable gait*. Note the mass budget
(4 × 20 g = 80 g of 4045 g, ~2 %) is **not** the binding constraint — swing
inertia is. This is P1 quantified: on this robot, a gram at the paw is worth far
more than a gram in the girdle.

## 5. Specified paw structure

```
        metatarsus (CF tube)
              │
        ┌─────┴─────┐   aluminium paw carrier, bonded insert
        │  [ PCB ]  │   MEMS barometer + local ADC, potted
        │   ╱───╲   │
        │  ╱ air ╲  │   moulded TPU dome with an engineered air cavity
        └─╱───────╲─┘
         ╲_________╱    TPU ~80A contact surface  (mu 0.8-1.2 on hard floor)
```

| Item | Choice | Note |
|---|---|---|
| Principle | **MEMS barometer under a sealed elastomer dome** | `[sourced]` proven on quadruped feet (Unitree Go1 end-effector, ≥40 N repeated impact); sensitivity and range tuned by the dome geometry and cavity volume, not by the part |
| Why not a load cell | 3-axis load cells in this range are **tens of grams** and rigid | violates §4 and removes the compliance the pad exists to provide |
| Why not strain gauges on the bone | measures limb load, **not contact** | same categorical failure as §3(b); also needs the tube instrumented and temperature-compensated |
| Mass target | **≤ 8 g** `[assumed]` incl. pad, carrier and PCB | leaves margin under the 20 g rule |
| Output | normal force + **contact flag**, ≥1 kHz | the flag is a comparator on the raw signal, so it is available with no filtering delay |
| Interface | joins the limb's existing CAN-FD node | no new bus (ADR-0005) |
| Tangential force | **from the joint-end load cells**, fused with the paw normal | the paw gives the well-conditioned normal; the joints give shear. Together they beat either alone. |

**The pocket already exists.** [ASSEMBLY_SPEC §1](ASSEMBLY_SPEC.md) already
specifies the paw pad as *"cast/moulded TPU ~80A, compliant contact + tactile
sensor pocket"* — this spec fills that pocket.

## 6. Beyond the paw

The user's framing was *tactile sensing **body structure***, so for completeness,
in decreasing order of value to balance:

| Location | Value | Verdict |
|---|---|---|
| **Paws (×4)** | requirement 1–3 above | **specified here** |
| **Shin / metatarsus** | obstacle strike detection while swinging | ⏸ deferred — no balance role; revisit for obstacle traversal |
| **Body shell** | landing detection for the ADR-0007 righting reflex | ⏸ deferred to the righting milestone; a fall-detect IMU covers the trigger, contact covers the *end* |
| **Whiskers** | biomimetic, genuinely useful for a cat near obstacles | ⏸ out of scope — no balance role |

Only the paws are on the M8 critical path. The others are recorded so the
structure can carry provision (routing, pockets) rather than being retrofitted.

## 7. What is owed

- `[owed]` **Dome geometry design** — the force range is set by cavity volume and
  wall thickness, and needs FEA or a moulding trial. §2's range is the target, not
  a solved geometry.
- `[owed]` **Drop test** to characterise the real touchdown impulse; §2's 100 N
  is the land transient standing in for an unmodelled impact.
- `[owed]` **Barometer part selection** and its overpressure rating vs the 100 N
  survival case.
- `[owed]` **Creep/hysteresis** of TPU under sustained load — the crawl holds a
  foot loaded for 4.5 s, which is a long time for an elastomer.
- `[owed]` A **fusion estimator** combining the paw normal with the joint-end
  shear; §5 asserts the combination is better but nothing has been designed.

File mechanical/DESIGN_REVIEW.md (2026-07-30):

# Mechanical Design Review — first critical pass

Reviewer: **lead** · Date basis: post-M4 (real mass, static stability) ·
Status of findings: **first-pass calculations, not verified hardware**

This reviews the mechanical design as a whole — [LEG_TENDON_SPEC](LEG_TENDON_SPEC.md),
[SPINE_TAIL_SPEC](SPINE_TAIL_SPEC.md), the [CAD models](cad/), and the M4 mass
model — looking for gaps and cross-artifact contradictions rather than
summarising what is already written.

**Estimate quality warning.** Every number below is a first-pass calculation from
placeholder geometry with assumed material properties (CF tube E ≈ 70 GPa
quasi-iso, σ_allow ≈ 400 MPa; motors ≈ 5.5 g/cm³). They are strong enough to
*direct attention*, not to size hardware. Each finding states what would confirm
or dismiss it.

---

## What is in good shape

- **The tendon hardware chain is coherent** — cable → pulley → bearing → routing
  → static-hold brake all trace from one design load with stated assumptions.
- **The static/dynamic bearing split** (§3.2) is the strongest single call in the
  specs: sizing fatigue life to the *continuous trot* and brinelling to the *rare
  land transient* is what keeps the bearings small. Correct reasoning.
- **The transient-vs-duty distinction** is what makes a ~450 N peak buildable.
- **Moment arms are now validated by the real budget**, not guessed: after the
  F1/F2 rebuild the spine's 0.030 m arm puts continuous tension at ~12 N, safely
  below the RoboCat band — it has margin to spare.

---

## F1 — Mass apportionment contradicts P1 (major) — ✅ RESOLVED

The M4 budget allocates **24 % of body mass to the limbs**, justified from feline
biology. But a biological limb's mass is largely **muscle**, and P1/ADR-0003
*deliberately relocate the muscle (motors) into the girdles*. Applying a
biological limb fraction to a tendon-driven robot double-counts the actuator.

A bottom-up count of the specced hardware disagrees by more than 2×:

| Per leg | Estimate |
|---|---|
| Sheaves (Ø56/50/28 Al, 45 % lightened) | 44 g |
| Bones (8 mm × 1 mm CF tube ×4) | 10 g |
| 6 miniature bearings, 3 shafts | 15 g |
| Cable + terminations, brackets | 11 g |
| **Total** | **≈ 80 g** |

vs **200 g budgeted** (hind). Even doubling my estimate for unmodelled parts
(sheaths, foot pad, fasteners) the legs land near **~120 g**, i.e. limbs ≈ **15 %**
of body, not 24 %.

Meanwhile the **girdles are under-budgeted**. They must contain the motors:

| Girdle contents | Estimate |
|---|---|
| 31 motors @ Ø16×28 mm ≈ 31 g | 960 g |
| 31 driver boards @ ~5 g | 155 g |
| Battery `[assumed]` | 300 g |
| **Subtotal** | **≈ 1415 g** |

vs **980 g budgeted** — a **~435 g shortfall**, before girdle structure.

The *total* still lands near 3.0 kg (the errors cancel), which is why this was
invisible: **the total is right and the distribution is wrong.**

> **Consequence:** the real machine is *more* mass-centralised than modelled —
> which is what P1 predicts and is good for agility — but CoM, the fore/hind
> split, and swing inertia are all computed from the wrong distribution.
>
> **To confirm:** pick a candidate motor (also gates `Kt`/bus voltage) and weigh
> or source-datasheet it; then re-derive the budget bottom-up instead of from the
> biological 24 %.

## F2 — The 60/40 front-heavy split is probably wrong (major) — ✅ CONFIRMED & FIXED

M4 solved the girdle masses to hit a **59.9 % fore** split, making the *front*
girdle heavy (700 g) to absorb head + neck. But per ADR-0005 / the board outline,
the motors are **not** distributed that way:

| Cluster | Motors |
|---|---|
| Shoulder girdle | 12 (fore legs) |
| **Pelvic girdle** | **19** (hind legs + 6 spine + 1 tail) |

At ~31 g each that is **589 g in the pelvis vs 372 g in the shoulder** — the
motor mass leans *rearward*, partly cancelling the head/neck. The true split may
be near-balanced or even rear-heavy, not 60/40 fore.

> **Why it matters:** M4's static stability margin is a CoM-vs-support
> calculation. Move the CoM rearward and the margins change directly — and the
> current gait already tips toward the **rear** edge (every phase is
> "STABLE (rear edge)"). This is the finding most likely to alter a result we
> have already published.
>
> **To confirm:** recompute `quarter_masses` with motors placed in their actual
> clusters rather than folded into girdle lumps, then re-run the stability sweep.

## F3 — The links are never structurally sized (major) — ✅ RESOLVED

The specs size the *cable, pulleys and bearings* to ~1 kN but never size **the
bones themselves**. That matters because an offset tendon does not merely
compress a link — it **bends** it: a cable running at radius `r` applies
`M = T·r` about the section.

First-pass 8 mm OD × 1 mm wall CF tube (I = 137 mm⁴):

| Link | T (N) | r (mm) | M (N·m) | bending σ | total σ | SF vs ~400 MPa |
|---|---|---|---|---|---|---|
| **Femur (hip)** | 447 | 28 | **12.5** | 364 MPa | **385 MPa** | **≈ 1.0** ⚠ |
| Tibia (stifle) | 305 | 25 | 7.6 | 222 MPa | 236 MPa | 1.7 |
| Metatarsus (hock) | 347 | 14 | 4.9 | 141 MPa | 157 MPa | 2.5 |

**The femur is at the material limit (SF ≈ 1.0)** in the land transient.
Euler buckling is **not** the issue (tibia P_cr ≈ 10.5 kN, SF ≈ 34) — bending is.

> ### ⚠️ Correction to this finding
> The first version of F3 claimed an "irony": that the *large hip moment arm
> chosen to cut cable tension* was what maximised femur bending, so the two
> objectives conflicted. **That was wrong.** Since `T = τ/r`, the moment is
> `M = T·r = (τ/r)·r = τ` **identically** — the link's bending moment is simply
> the joint torque, and is *independent of the moment arm*. Growing `r` reduces
> cable tension and leaves link stress untouched. There is **no trade** between
> the two; they are independent levers. The understrength finding itself stands —
> only the explanation was wrong.

> **Resolved:** purely a section problem. A **graded tube set** (femur Ø12×1,
> tibia Ø10×1, metatarsus/paw Ø8×1) lifts every link to **SF ≈ 2.8–3.1** for
> **+2.7 g per leg** and **+0.9 % swing inertia** — the added material sits
> proximally, where the inertia lever is short. Specified in
> [LEG_TENDON_SPEC §3.5](LEG_TENDON_SPEC.md).
> Still owed: combined bending **+ torsion**, and local crushing where a pulley
> or clevis clamps the tube — both need real joint detail (F5).

## F4 — Girdle width unresolved (moderate) — ✅ RESOLVED

The packaging study sizes each girdle at **142 mm wide** against a **96 mm leg
track**, so the motor banks protrude past the body sides, and the pelvic girdle
grows to 91 mm tall. Documented in [cad/README](cad/README.md) but never
resolved. Options already noted: reorient motors, spread the bank along the
torso, or take the variable-radius-pulley reduction (spine 6 → 3).

F1 makes this *more* urgent: if girdle contents are ~435 g heavier than budgeted,
they are also bulkier than drawn.

> **Resolved by re-orienting the motors, not by shrinking the bank.** The banks
> were laid **axis-along-Y**, so each motor's 28 mm length projected *sideways*.
> Standing them **upright (axis-along-Z)** puts that length into girdle height —
> where there is room — and reduces the footprint to a grid of Ø16 circles.
> With compact 3 × 2 banks at y = ±21 and the spine/tail bank offset rearward:
>
> | | before | after |
> |---|---|---|
> | Girdle width | 142 mm (> 96 mm track) | **87 mm — fits** |
> | Pelvic girdle height | 91 mm | **52 mm** |
> | Girdle collision on the 195 mm spine | 108 + 108 → overlap | **64 + 88, ~119 mm clear** |
>
> Note this did **not** require the variable-radius-pulley motor reduction or a
> wider body — the motor count is unchanged. It also relieves the pelvic
> density/thermal hot-spot the electronics outline flagged: both girdles are now
> the same height. Upright spools also pay cable off in the fore-aft/vertical
> plane, which is the direction the tendons actually run.

## F6 — Motor mass makes the 3 kg body infeasible (BLOCKING) — ✅ RESOLVED by ADR-0008

Raised by the [motor down-select](../docs/notes/motor-downselect.md). F1 assumed
~31 g/motor; a real QDD module meeting the torque requirement (SteadyWin
GIM3505-9 class) is **131.7 g — 4.2× heavier**.

| Configuration | Motors | Motor mass | % of 3 kg body |
|---|---|---|---|
| Full antagonistic (ADR-0002) | 31 | 4083 g | **136 %** |
| CAD reduced (ankle spring) | 24 | 3161 g | **105 %** |
| + variable-radius pulley | 16 | 2107 g | 70 % |

**The motors alone exceed the whole body budget.** This is the honest cost of
P1: relocating 24–31 muscles into the torso means the torso must carry 24–31
motors. Ways out — scale the body to ~6–9 kg, cut motor count, or cut the torque
requirement (thinner cable → smaller spool). Most likely a combination.

> **Resolved by [ADR-0008](../docs/DESIGN_DECISIONS.md).** Scaling the body up
> was rejected *on physics*: the motor-mass fraction is **invariant with scale**
> (191 % at 1.5, 3 and 9 kg alike) and gets worse under geometric scaling. The
> two levers that work are **sizing basis** and **motor count**: sizing to trot
> instead of the ×2.5 landing takes 24 motors from 191 % → 57 %, and the
> variable-radius pulley takes 24 → 16, closing the budget at **38 %** on the
> existing 3 kg body with **full articulation retained**. Target motor spec:
> ~1.1 N·m peak, ≤80 g. Hard landings become out-of-envelope for v1.
>
> Still open: motor count 24 → 16 invalidates the **F4 girdle packing**, and the
> real motor envelope differs from the Ø16 × 28 mm placeholder — re-pack needed.

## F5 — No assembly / manufacturing pass (gap) — ✅ RESOLVED

Across all mechanical docs there is essentially **one** mention of
manufacturability (the CAD README stating it is not a manufacturing model). Not
yet addressed: fabrication method per part, tolerances and fits, fastener
strategy, cable **termination** and **re-tensioning** access, and how a joint is
physically assembled around its pulley and bearings. This is expected at this
stage — recording it so it is not mistaken for completeness.

> **Resolved by [ASSEMBLY_SPEC.md](ASSEMBLY_SPEC.md)**, which also closes the two
> checks F3 deferred:
> - **Combined bending + torsion.** An unguided cable reaching the bone with the
>   27 mm lateral offset implied by the girdle layout costs ~24 % of the femur's
>   safety factor (2.84 → **2.17**) — still above 2, so not a blocker, but a
>   **limb-root idler** that turns the cable into the bone's plane recovers it
>   fully and is cheap.
> - **Local crushing.** Through-bolting is survivable at ≥4 mm pin (112 MPa vs a
>   ~150 MPa transverse allowable) but is *not* recommended — it cuts fibres and
>   leans on the least trustworthy number in the design. **20 mm bonded aluminium
>   inserts** carry the same load at 0.71 MPa adhesive shear, SF > 14.
>
> The spec also fixes fabrication method per part, the joint stack-up (with the
> rule that **the sheave keys to the DISTAL link**), H7/h6 fits, spliced-eye
> terminations (knots lose 30–50 % in UHMWPE), and **±5 mm re-tensioning travel**
> sized from UHMWPE creep — with the constraint that adjusters must be reachable
> without de-mounting a limb, and that re-tensioning must be followed by the FR7
> calibration routine.

## F7 — The walk is LATERALLY unstable (3D geometry) — ✅ RESOLVED by ADR-0009

Every stability result so far came from the 2D-sagittal support *interval*, which
each document correctly flagged as **necessary but not sufficient**. Giving the
legs their real lateral track offsets (3D **geometry** — no new DOF, no motors)
makes the true ground-plane **support polygon** computable for the first time.
It disagrees with the 2D result:

| | 2D sagittal interval | **True support polygon** |
|---|---|---|
| Worst margin over the cycle | **+24.6 mm** (stable everywhere) | **−28.7 mm** (unstable) |

With three feet down the support triangle is skewed to one side while the CoM
sits on the mid-sagittal plane, so it falls **outside** the triangle for roughly
half the cycle. This is the classic reason quadrupeds **sway** during a crawl.

**What was tried (all measured, not assumed):**

| Lever | Result | Costs motors? |
|---|---|---|
| Re-order the leg phase sequence (all 24 permutations) | best **−22.7 mm** — still unstable | no |
| **Widen the track** (96 → 260 mm) | **−47.7 mm — WORSE** | no |
| Shift the CoM forward alone | best **−8.3 mm** at +40 mm | no |
| **Lateral body sway ~40 mm** | **+5.7 mm — works** | **yes** |
| Forward CoM +30 mm **and** sway 25 mm | **+8.1 mm — works** | yes (less sway) |

Widening the track being *counter-productive* is the surprise: the critical edge
is the **diagonal** from the far front foot to the near rear foot, and widening
only rotates that diagonal further away from the CoM.

**The decision this forces.** Static stability needs a **lateral DOF** for sway.
ADR-0006 already specifies spine lateral bend as a target, but
[ADR-0008](../docs/DESIGN_DECISIONS.md) budgeted motors for the sagittal DOF only
(16 motors, 38 % of body). Options:

1. **Add spine lateral DOF** (+3 motors → 19, ~46 % of body) — re-opens ADR-0008's
   mass closure, which had ~35 % left for structure.
2. **Accept dynamic walking** — drop the static-stability requirement, as most
   real quadrupeds do when trotting. Cheapest, but changes what the controller
   must guarantee.
3. **Bias mass forward + a smaller lateral DOF** — the +30 mm/25 mm combination
   above needs less sway authority than 40 mm alone.

**Resolved: [ADR-0009](../docs/DESIGN_DECISIONS.md) adds the spine LATERAL DOF
(16 → 19 motors).** Chosen because it is the only option that both *works* and
*was already in the design*: P2 says the whole body may curve and ADR-0006
already specifies lateral yaw — we had built only the sagittal subset. Authority
was checked, not assumed: at ADR-0006's ±15°/segment lateral ROM the CoM sways
**42.8 mm**, against the ~40 mm needed. Leg abduction was rejected (more motors,
and it puts mass in the limbs, fighting P1); dynamic walking was rejected for now
because the dynamics milestone does not exist yet, so it would move the whole
burden onto an unbuilt controller.

⚠️ The cost is real: structure margin falls **27.3 % → 19.6 % (587 g)**. It still
closes, but should be re-checked against real printed-part masses.
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

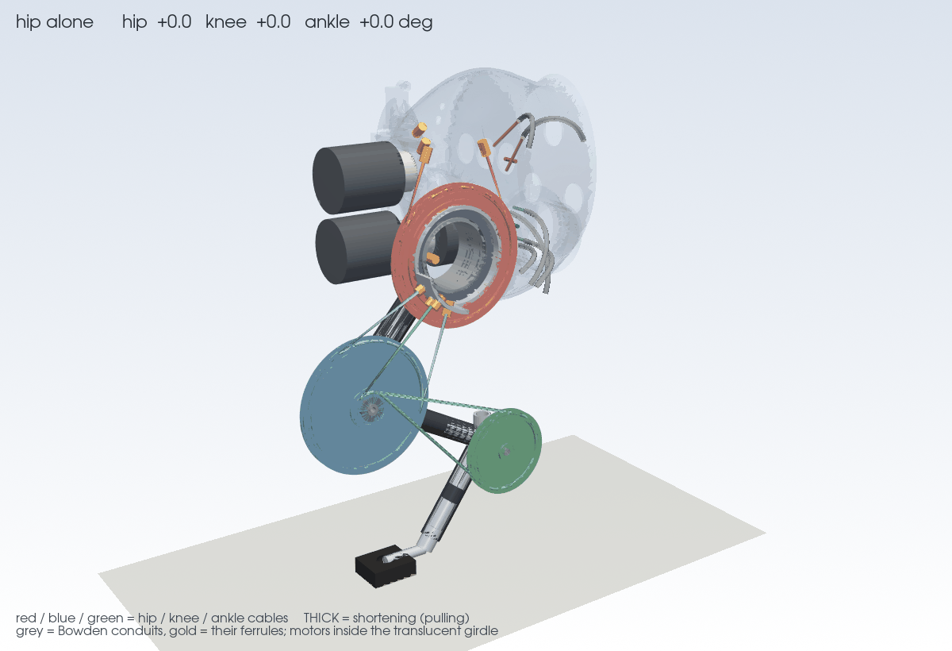
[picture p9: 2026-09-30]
mechanical/cad/leg_drive_3d.gif

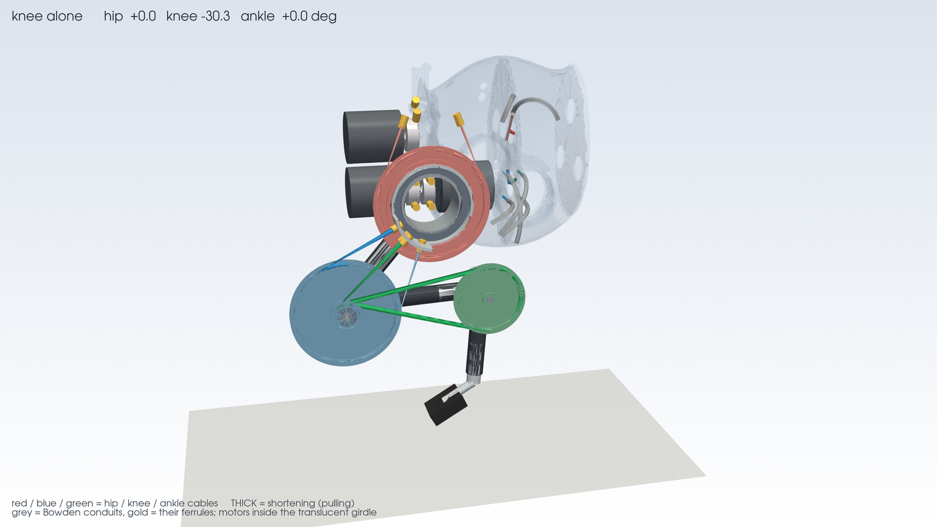
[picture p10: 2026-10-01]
mechanical/cad/leg_drive_3d_still.png

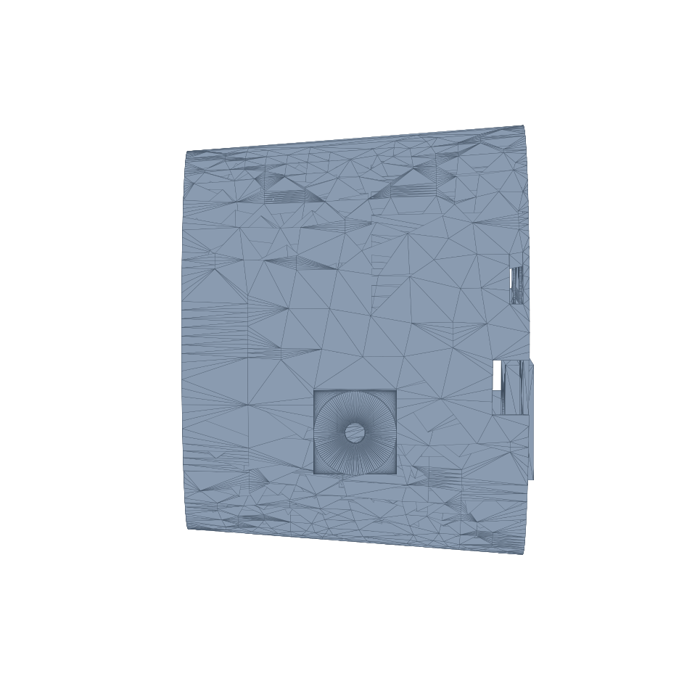
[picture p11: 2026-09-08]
mechanical/cad/tomcat_girdle_front.png

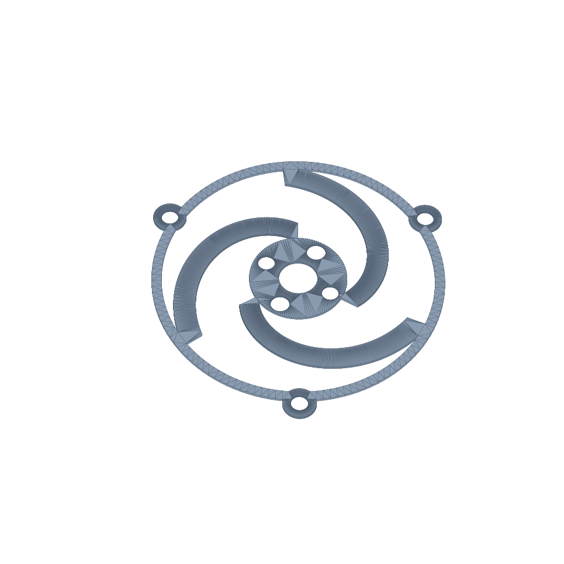
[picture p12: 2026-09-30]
mechanical/cad/g3_flexure_spine.png

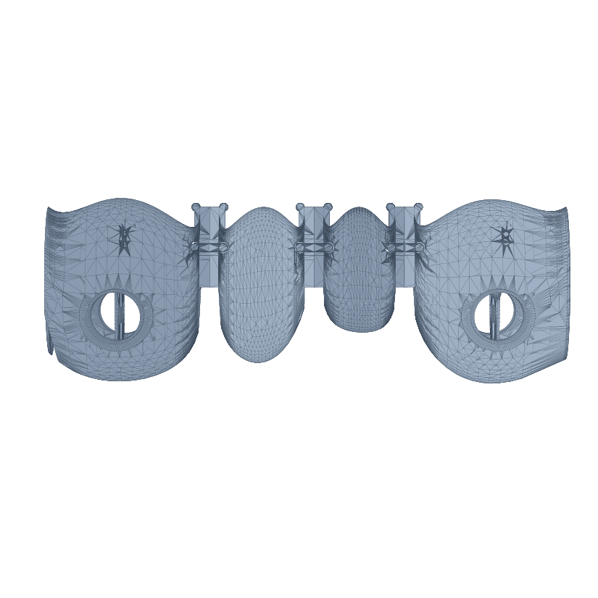
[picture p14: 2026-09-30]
mechanical/cad/tomcat_trunk_side.png

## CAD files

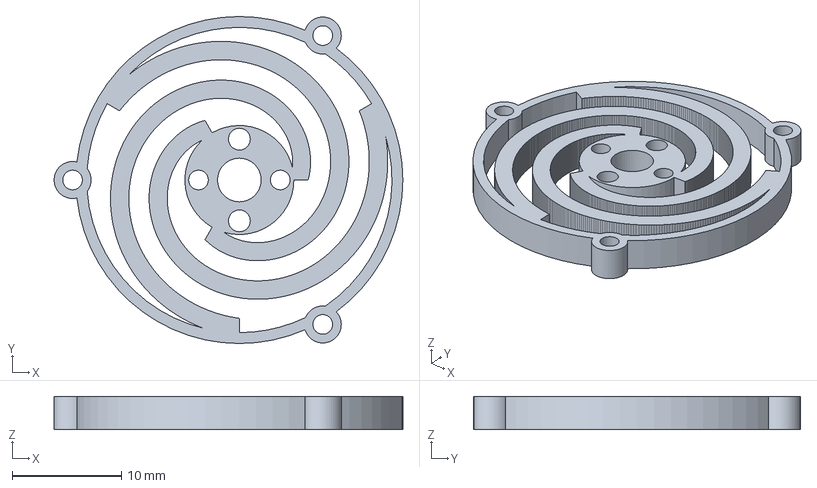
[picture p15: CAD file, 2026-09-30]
mechanical/cad/g3_flexure.step
32.0 x 30.0 x 3.06 mm

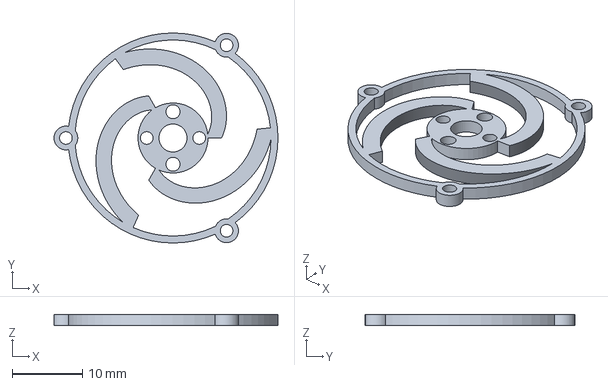
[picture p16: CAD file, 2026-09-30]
mechanical/cad/g3_flexure_spine.step
32.0 x 30.0 x 1.63 mm

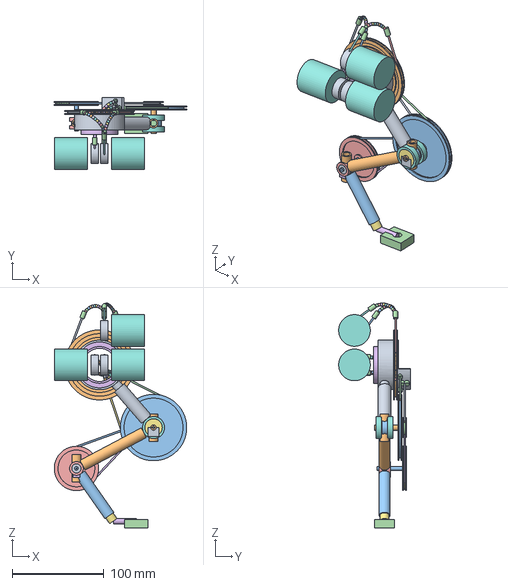
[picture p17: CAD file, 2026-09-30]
mechanical/cad/tomcat_leg_detail.step
144.2 x 78.0 x 244.9 mm

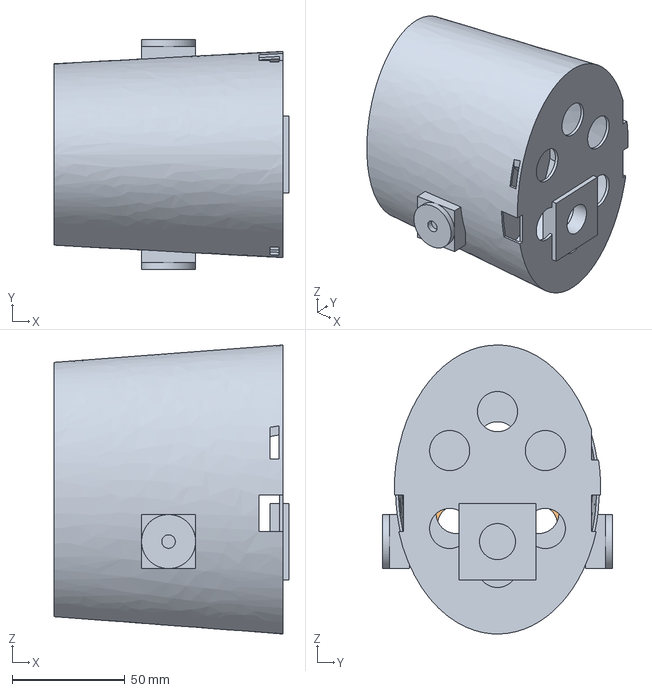
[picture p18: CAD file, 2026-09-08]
mechanical/cad/tomcat_girdle.step
104.2 x 102.0 x 128.2 mm

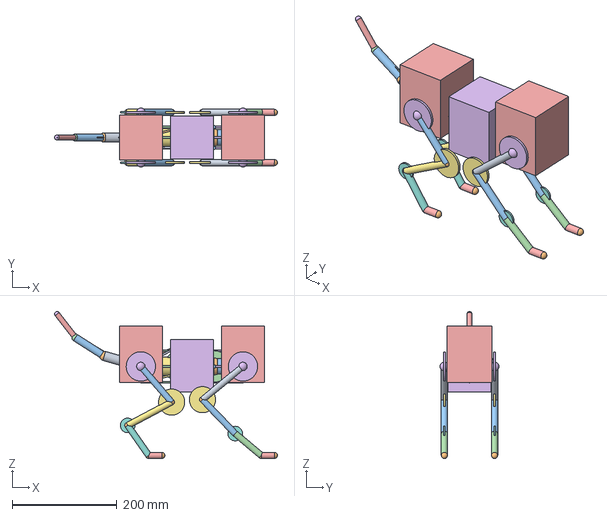
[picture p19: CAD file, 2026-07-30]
mechanical/cad/tomcat_packaging.step
426.0 x 112.7 x 281.1 mm

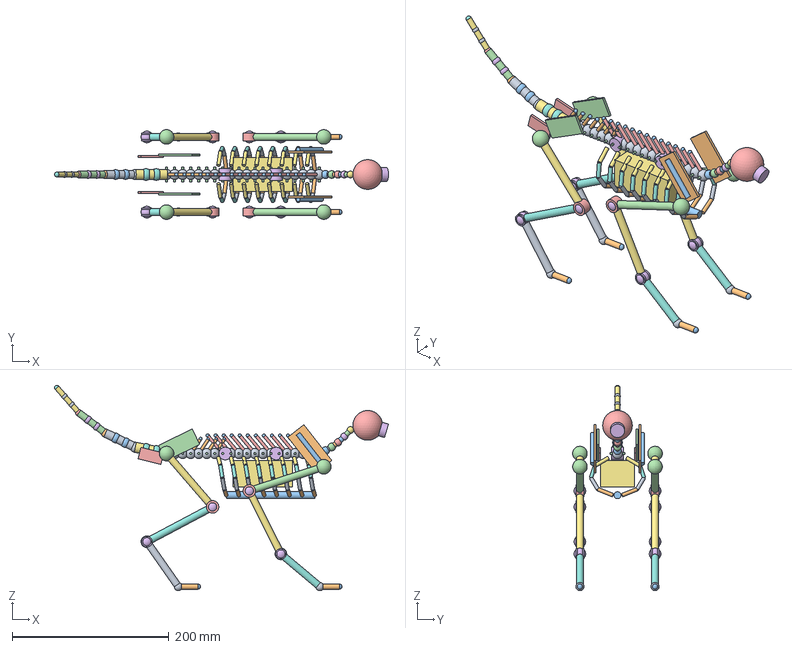
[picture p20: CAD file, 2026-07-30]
mechanical/cad/tomcat_skeleton.step
426.7 x 114.7 x 262.4 mm

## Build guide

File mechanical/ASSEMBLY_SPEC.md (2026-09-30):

# TomCat — Assembly & Manufacturing Spec (first pass) — closes review F5

Owner: **tomcat-mechanical** · Closes [DESIGN_REVIEW](DESIGN_REVIEW.md) **F5**,
and the two checks **F3** deferred (combined bending+torsion, local crushing).

Every prior mechanical document specified *what the parts must withstand*. None
said **how a part is made, how a joint goes together, or how a cable is
terminated and re-tensioned**. This is that document.

Label legend: `[sourced]` traceable to another spec/ADR · `[assumed]` first-pass
engineering guess · `[owed]` needs a vendor part or a test.

---

## 0. Closing the two F3 debts

### 0.1 Combined bending + torsion

A limb bone carries bending `M = τ_joint` (LEG_TENDON_SPEC §3.5). It *also*
carries **torsion** if the tendon reaches the bone with a lateral offset `e` —
which it does, because the motor spools sit inboard (y ≈ 21 mm) while the limb
plane is outboard (y ≈ 48 mm). Thin tube: `J = 2I`, so `τ_shear = T·e / 2Z`,
combined by von Mises `σ_vm = √(σ_b² + 3τ²)`.

Femur, Ø12 × 1 CF, hip land case (M = 12.36 N·m, T = 447 N):

| lateral offset `e` | torsion | σ_vm | **SF** |
|---|---|---|---|
| 0 mm (cable in the bone's plane) | 0 | 141 MPa | **2.84** |
| 10 mm | 4.5 N·m | 147 MPa | 2.71 |
| **27 mm (cable run straight from the girdle)** | 12.1 N·m | 184 MPa | **2.17** |

**Finding:** an unguided cable costs ~24 % of the femur's safety factor, but even
the worst case stays above SF 2. **Design rule: fit an idler at the limb root
that turns the cable into the bone's sagittal plane** — it recovers the full
SF 2.84 and is cheap. If omitted, SF 2.17 is still acceptable, so this is an
optimisation, not a blocker.

### 0.2 Local crushing at a pulley / clevis clamp

Pin bearing on a thin CF wall is `σ = F / (d·t)`, against a transverse allowable
of ~150 MPa `[assumed — CF transverse strength is highly layup-dependent]`:

| pin Ø | bearing stress | verdict |
|---|---|---|
| 3 mm | 149 MPa | marginal |
| **4 mm** | **112 MPa** | OK |
| 6 mm | 74 MPa | comfortable |

**Through-bolting is survivable at ≥4 mm but is NOT the recommended joint.**
Drilling a pultruded tube cuts load-bearing fibres, and the transverse allowable
is the least trustworthy number in this document. Use **bonded aluminium end
inserts** instead: they transfer load into the tube wall as *adhesive shear over
a long area* rather than point bearing.

| insert engagement | adhesive shear at 447 N | vs ~10–20 MPa structural epoxy |
|---|---|---|
| 15 mm | 0.95 MPa | SF > 10 |
| **20 mm** | **0.71 MPa** | SF > 14 |

**Rule: 20 mm bonded insert engagement**, ≥10× margin, and no drilled laminate.

---

## 1. Fabrication method per part

| Part | Method | Material | Note |
|---|---|---|---|
| Limb bones (femur/tibia/metatarsus) | **cut to length from stock tube** | pultruded CF, Ø12/Ø10/Ø8 × 1 mm | graded sections per LEG_TENDON_SPEC §3.5 |
| Bone end fittings | **turned**, bonded into the tube | 6061-T6 | 20 mm engagement (§0.2) |
| Joint clevises / forks | **CNC-milled** | 6061-T6 | carries the bearing bores |
| Joint sheaves (Ø56/50/28) | **turned**, hard-anodised groove | 6061-T6 | groove r ≈ 0.85 mm `[sourced: §2]` |
| Vertebrae, girdle shells, scapula/pelvis blades | **3D printed** (SLS nylon or MJF) | PA12 | complex, low-stress, non-critical form |
| Spine spinous-process pulley posts | **CNC-milled** | 6061-T6 | this *is* the 30 mm dorsoventral tendon moment arm |
| Spine **lateral** pulley posts (±20 mm, per actuated vertebra) | **CNC-milled** | 6061-T6 | this *is* the 20 mm lateral moment arm (ADR-0009 f/u). Shortening it to the bare transverse process puts the base lateral joint **over motor peak** |
| Motor / driver housings | **3D printed** | PA12 | cover plates for access, §4 |
| Paw pads | **cast / moulded** | TPU ~80A | compliant contact + **sealed dome over a MEMS barometer** — see [TACTILE_SENSING_SPEC](TACTILE_SENSING_SPEC.md). ⚠️ **μ ≥ 0.70 is a requirement again (NFR16 / ADR-0019)** — withdrawn by ADR-0010 for the crawl crossover, reinstated because the spine's *balance* action needs ground reaction to shift the CoM. Published PU-on-concrete is 0.8–1.2 so it should pass, but it is now load-bearing. `[owed: measure on the intended floor]` Also **mass ≤ 20 g per paw** (ADR-0012). |

Rationale: metal only where load or precision demands it (bearing bores, sheave
grooves, bonded joints); printed everywhere else to keep mass and cost down.
**Nothing here is drawn to a machinable level yet** — these are methods, not
shop drawings `[owed]`.

## 2. Joint assembly stack-up

Every actuated joint is a hinge about the lateral axis. Assembly order, outside
in, per side:

```
   clevis arm (distal link)                    clevis arm (distal link)
   ├─ retaining circlip                        ├─ retaining circlip
   ├─ deep-groove ball bearing  ── shaft ──    ├─ deep-groove ball bearing
   │    (bore H7, press)          (h6)         │
   └───────────  SHEAVE, keyed/clamped to the DISTAL link  ──────────┘
                          ▲
              proximal link tongue rides between the arms
```

Critical rule: **the sheave is fixed to the DISTAL link, not the shaft.** Cable
tension on the sheave must rotate the distal link about the joint — if the sheave
were fixed to the shaft or the proximal link, the tendon would do no work.

| Interface | Fit | Reason |
|---|---|---|
| Bearing OD → clevis bore | **H7** | locating, light press |
| Shaft → bearing bore | **h6** slip / k6 light press | serviceable |
| Sheave hub → distal link | keyed or split-clamp | must transmit full joint torque |
| Insert OD → tube ID | **0.05–0.15 mm bond gap** | epoxy needs a controlled glue line |

Bearings are sized in LEG_TENDON_SPEC §3.2 (static C₀ ≥ 1.5 kN, dynamic C ≥ 0.3 kN)
`[sourced]`. Exact part numbers `[owed: BOM pass]`.

> ✅ **M123 ([ADR-0114](../docs/DESIGN_DECISIONS.md)): the HIP is not this stack
> any more.** It is hollow: the trunk carries a **stub** on the hip axis
> (Ø40 × 36), and the femur's **hub** (Ø54) turns on it in two thin-section
> bearings (40 × 50 × 6, 6708 class `[assumed]`), bearing OD H7 in the hub, stub
> h6 in the bearing bore. The hip sheave is an annulus on the hub's rim (still
> on the DISTAL link), and the femur's insert bonds to a root tube off the hub.
> The knee and ankle Bowden conduits pass through the stub's bore and end in
> ferrules seated in the hub's wall, 30 mm off the axis: assemble the conduits
> through the stub BEFORE the hub goes on. The knee and ankle keep the stack
> above.

## 3. Cable termination

UHMWPE (Dyneema) is slippery and **loses 30–50 % of its strength in a knot** —
knots are not acceptable at a ~465 N design load.

| Location | Method | Why |
|---|---|---|
| **Joint end** | **spliced eye (Brummel) over a thimble**, onto the anchor pin | a splice retains ~90–100 % of line strength; a knot would not |
| **Spool end** | 3–4 dead turns + **clamp screw** | the capstan effect means the anchor itself sees only a few % of tension |
| Anti-creep prep | **heat-set / pre-tension** the cable before final length setting | takes out constructional stretch so §4 only has to absorb true creep |

## 4. Re-tensioning — access and travel

UHMWPE **creep** is the reason this section exists (LEG_TENDON_SPEC §2 flags it
as the cable's main drawback). Tendons will need periodic take-up.

- **Mechanism:** a **threaded anchor (eye-bolt) at the JOINT end**, adjusted with
  a hex key. Chosen over spool-side rewind because it acts directly on the loop
  that stretched and needs no motor re-indexing.
- **Travel required:** cable runs are ~0.15–0.25 m; UHMWPE service creep of
  1–2 % gives **1.5–5 mm**. Specify **±5 mm** of adjuster travel `[assumed]`.
- **Access:** each girdle and limb-root housing gets a **removable cover plate**
  on the outboard face; the joint-end adjusters must be reachable **without
  removing a bearing or de-mounting the limb**. This is a hard constraint on the
  housing design, recorded here so it is not discovered late.
- **Calibration hook:** re-tensioning changes the tendon-to-joint zero, so it
  must be followed by the **FR7 calibration routine** (zero tendon tension and
  joint range) — a mechanical action with a firmware consequence.

## 5. Assembly sequence (whole robot)

1. Bond inserts into all bone tubes; cure; **verify pull-out on a coupon** `[owed]`.
2. Build each limb: clevis + bearings + shaft + sheave per §2, working distal → proximal.
3. Populate girdle backplanes with motor modules and driver boards
   ([BOARD_OUTLINE](../electronics/BOARD_OUTLINE.md)); fit the girdle covers last.
4. Mount limbs to scapula/pelvis; fit the limb-root idlers (§0.1).
5. Route tendons girdle → idler → joint sheave; splice the joint ends (§3).
6. Pre-tension, heat-set, set length at the adjusters (§4).
7. Fit the ribcage and the electronics/battery bay inside it.
8. Run the FR7 calibration routine; verify per-tendon tension against ADR-0004
   sensing before any load test.

## 6. What is still owed

> ✅ **Partly closed by M36** ([ADR-0041](../docs/DESIGN_DECISIONS.md)):
> `cad/tomcat_leg_detail.py` is manufacturable geometry for one hind leg — bonded
> inserts with a modelled glue line, clevis/tongue joints with H7 bearing bores,
> turned sheaves whose pitch line *is* the tendon moment arm, the §0.1 root idler,
> the return spring and the tactile pad. It exports STEP/STL and **verifies its own
> dimensions**, which is how the discrepancies now flagged in LEG_TENDON_SPEC were
> found. Three things this section assumed did not survive it:
>
> - **The 20 mm insert rule does not fit the distal links** — two of them fill 81 %
>   of a metatarsus. §0.2's own 15 mm / SF > 10 point is used instead.
> - **The paw phalanx cannot be a bonded tube at all.** Its 25 mm span leaves 10 mm
>   after joint hardware; two inserts plus a gap need ≥ 14 mm. It is a solid turned
>   or printed stub, which §1's fabrication table does not list.
> - **Inserts must be turned hollow.** A solid Ø9.9 × 20 plug is 4.2 g against a
>   4.8 g femur tube; a bonded joint needs shear area, not a plug.
>
> Still owed: shop drawings proper, and the BOM.

- **Shop drawings / a real BOM with part numbers** — this document specifies
  methods and fits, not manufacturable geometry.
- **Bond coupon test** for the insert (the whole 20 mm engagement rests on an
  assumed 10–20 MPa epoxy allowable).
- **CF transverse allowable** — the 150 MPa in §0.2 is the least trustworthy
  number here; it decides whether through-bolting is ever acceptable.
- **Tolerance stack-up** across a limb — individual fits are specified, but the
  accumulated effect on foot position is not analysed. (M36 swept the **ROM** for
  self-interference — worst non-adjacent clearance **+15.4 mm**, clean — but that
  is kinematic clearance, not tolerance accumulation.)
- **Serviceability review**: §4 asserts adjusters must be reachable without
  disassembly; nothing has verified that against the actual housing geometry.

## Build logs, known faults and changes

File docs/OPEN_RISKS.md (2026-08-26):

# Open risks and how to close them

The model carries **35 `[owed]` items and 110 `[assumed]` values** (recount with
`grep -ro '\[owed\]' --include='*.py' --include='*.md' --include='*.rs' . | wc -l`).
Most of them cannot change a decision, and treating them as equal work would waste
effort on the wrong ones. This ranks them by **what breaks if the assumption is
wrong**, and says concretely how each is closed.

The short version:

> **One cheap measurement de-risks almost the whole design: buy a motor and weigh
> it.** It does not need the robot to exist. The paw drag-test was the other critical
> item until M29 ([ADR-0034](DESIGN_DECISIONS.md)) downgraded it — NFR15 survives from
> μ ≥ 0.6, which any dry floor clears. Everything else is either low-consequence, or a
> decision rather than an unknown.

⚠️ **Simulation cannot substitute for either.** M17 ([ADR-0022](DESIGN_DECISIONS.md))
added an independent MuJoCo cross-check, and it validated the *model* — it says
nothing about R1 or R2. No physics engine knows what a motor weighs or how grippy a
pad is; feeding an assumed value in returns the assumed value. **Measurement checks
the inputs, simulation checks the model.**

---

## 1. Critical — these can break the design

### R1. Motor mass — 132 g `[assumed from one reseller page]`

**Why it is critical.** The whole mass budget was already re-derived once when the
72 g class target turned out not to exist (ADR-0010). It now rides on a *single
vendor page* for the SteadyWin GIM3505-9, which the down-select note itself calls
"a representative *class*, not a final part".

| real motor mass | body mass | verdict |
|---|---|---|
| **132 g** (assumed) | 4.04 kg | NFR5 holds |
| 160 g | 4.58 kg | **budget breaks** |
| 200 g | 5.34 kg | **budget breaks badly** |

There is only **21 % margin**. And a heavier body raises every torque, which
raises the motor needed — the spiral ADR-0010 showed converges *only* because the
chosen part has headroom.

**How to fix:** buy **one** motor and weigh it. ~£60 and a week's shipping.
Also weigh the driver separately to settle whether the 131.7 g figure includes it.

**Do this first.** It is the cheapest action with the largest blast radius.

### R2. Paw friction μ — assumed ≥ 0.70 `[from literature, never measured]`

> ⬇️ **DOWNGRADED to SIGNIFICANT by M29** ([ADR-0034](DESIGN_DECISIONS.md)).
> The table below was **stale** — it predates M20's sway correction and cannot be
> reproduced from the current code. Re-derived on the exact viable set, **NFR15 is
> met from μ ≥ 0.6**, not μ 0.70-with-no-margin:
>
> | stance | speed | μ 0.5 | **0.6** | 0.7 | 0.8 |
> |---|---|---|---|---|---|
> | 0.40 s | 50 cm/s | 47.6 | **52.6 ✅** | 57.7 | 62.7 |
> | 0.30 s | 67 cm/s | 45.3 | **48.1 ✅** | 50.9 | 53.7 |
>
> At the NFR16 floor of 0.70 the margin is **20 %**, not zero. A typical dry floor
> clears 0.6 comfortably, so this is no longer a design-breaker. The drag test is
> still worth doing; it is no longer urgent.

~~**Why it is critical.** μ ≥ 0.70 (NFR16) is met with **no margin at all**:~~

| floor μ | ~~envelope~~ **(stale, unreproducible)** | ~~NFR15?~~ |
|---|---|---|
| 0.5 | ~~40.2 mm~~ | ~~fails~~ |
| **0.70** | ~~48.1 mm~~ | ~~exactly meets~~ |
| 0.9 | ~~53.9 mm~~ | ~~meets~~ |

This number has had a strange history — withdrawn by ADR-0010 as a non-constraint,
then reinstated by ADR-0019 for a *different mechanism* (the spine's balance action
needs ground reaction). It is now load-bearing and sitting on a literature value
for "PU on concrete", not on this pad, this compound, or the intended floor.

**How to fix:** a **drag test**. Mould two or three TPU pads, load one with a
known weight, pull it across the intended floor with a luggage scale or a
force gauge, and read the ratio. Half a day, no special equipment. Test wet, dusty
and polished cases too — the failure mode is a *bad* floor, not a typical one.

---

## 2. Significant — these change a number, not viability

### R3. Battery energy density — 175 Wh/kg, 80 % usable `[assumed]`

Runtime spans **18–48 min** across plausible cell choices, against the 30 min in
NFR6. Nothing breaks; the specification moves.

**How to fix:** pick a real cell. This is procurement, not analysis.

### R4. The actuation ramp — 37 ms `[modelled, never benched]`

It is the **dominant term** in the balance latency budget (ADR-0016), and it
assumes a trapezoidal move with no torque droop. M12 showed the ramp itself
costs little because the legs are light, but that rests on the operational-space
inertia model.

**How to fix:** one leg on a bench, commanded to step its foot 74 mm mid-swing;
measure the time. Needs a leg to exist — so it is gated on the build.

### R5. Sustained trot thermal duty — **partly closed by M18**

~~Gated on having the motor.~~ It was not gated on hardware. A lumped-capacitance
model ([ADR-0023](DESIGN_DECISIONS.md), `thermal/`) now gives a prediction to
falsify instead of a blank:

| front girdle, 6 motors | continuous | one battery |
|---|---|---|
| trot, polished | **113.7 °C** | 67.1 °C |
| trot, **anodised** | 74.9 °C | 59.7 °C |

⚠️ **The battery is the thermal protection, and that is a coincidence** — a bare
girdle's ~47 min effective time constant outlasts the 30 min the pack can feed it.
(The 53 min first published was convection-only; see ADR-0023's correction.)
**Tethered or hot-swapped operation is out of spec** (NFR18). Centralising the
motors (P1) costs **38 %** of the rejection area.

**Anodising is the fix, and it does two things.** It drops the continuous case ~39 K,
*and* it shrinks the gap between battery-limited and continuous from **47 K to 15 K** —
so the design stops depending on the coincidence. Confirmed on a coupled run under
the kernel's conservation audit, with the runtime emergent (30.17 min vs `power.py`'s
30.16).

**The skin/winding gap is now answered** (M19, [ADR-0024](DESIGN_DECISIONS.md)):
the winding runs **+7.7 K** above the published skin at nominal joints, and
**1.9–30.7 K** across plausible ones. Anodised that puts the winding at 82.6 °C
continuous and the stator — which the rotor magnets sit against — at 78.7 °C.
Polished, the stator reaches 117.5 °C, past ordinary NdFeB grades.

**What is still owed:** the joint conductances are `[assumed]` and set the whole
gradient; copper loss is still the only source modelled (iron loss lands in the
*stator*, so it would redistribute as well as raise). The bench test is still worth
doing, but it now checks numbers rather than discovers them.

---

## 3. Low risk — flagged, but they cannot change a decision

| item | why it is low risk |
|---|---|
| **Structure mass** (296 g modelled vs 587 g allowed) | ~2× headroom; it would have to be twice wrong to matter |
| **Tendon friction μ / wrap** | decides *which* joints need a load cell (ADR-0004), not whether the robot works |
| **Driver board mass** (5 g) | 19 × a few grams, inside the structure margin |
| **Girdle structure allowances** (90 / 110 g) | loosest numbers in the mass model, but small |
| **NFR15 disturbance cases** | `[assumed]` scenarios — but a *stated* basis is the improvement over the capability figure they replaced (ADR-0017) |

These should stay flagged and stay unresolved until something cheap resolves them.

---

## 4. Not unknowns — decisions waiting for an owner

These are **costed options**, not risks. Each has a number attached and needs a
judgement, not an experiment.

| decision | the trade | status |
|---|---|---|
| **Joint moment arms 1.25×** | +23 % runtime (30 → 37 min) for a 70 mm hip sheave, plus mass/packaging/inertia ripple | ADR-0021, **not adopted** |
| **Leg abduction** | +42–58 % disturbance envelope for +4 motors, 528 g (13 % of budget) | ADR-0017, **rejected** — original basis ("NFR15 already met") no longer holds, but M27 says **do not reopen yet**: the controller cannot exploit the authority it already has, so more would be wasted mass (ADR-0032). |
| **Trot speed 50 cm/s** | slowed from 67 by the spine's friction cost | ADR-0020 — ⚠️ **NFR15 is no longer a reason** (M29: the fast gait meets it at μ ≥ 0.6, *and* has a better sensing margin). **Partly measured (M30, [ADR-0035](DESIGN_DECISIONS.md))**: the mechanism is confirmed but the cost is **~14 % at μ 0.70, not ~100 %**. Significance is marginal (n = 11, capped by low-μ runs falling), so **50 cm/s stands** — now blocked on controller quality, not on the model. |
| **Spine lateral ROM ±15°** | ±25° would give 119 mm envelope, no extra motors — but fights the biomechanics (lateral is the stiffest spine axis) | ADR-0015, **held** |

---

## 5. Genuinely unbuilt

**Electronics and firmware have specifications and no implementation** — 2 and 3
markdown files respectively, with one C header between them. That is not a *risk*
in the sense above (nothing is wrong), it is simply the largest piece of remaining
work.

ADR-0016 established these have a **comfortable** budget: the balance loop's
electronics pipeline has ~16 % influence on the envelope, so ordinary engineering
suffices and no exotic timing is needed. The specs to build against exist
([BOARD_OUTLINE](../electronics/BOARD_OUTLINE.md),
[INTERFACE](../firmware/INTERFACE.md), ADR-0005).

---

## 6. What the modelling can still settle on its own

Small, and honestly at the point of diminishing returns:

- **Regeneration** — currently credited at zero, so 27 W of mechanical work is
  written off. A backdrivable drive recovers some of it, which would improve NFR6.
- ~~**Trunk / dorsoventral `dH/dt`**~~ — **closed by M17** ([ADR-0022](DESIGN_DECISIONS.md)).
  Rather than computing each term, an independent MuJoCo model measured their
  aggregate effect on the only quantity they could change: the divergence rate is
  **2 % SLOWER** than LIPM predicts, so the reduced-order model is conservative.
- ⚠️ **NEW — the single-axis reduction.** M17 found the two diagonals topple along
  axes **52.4° apart**, which `StepPlant`'s fixed `projection` cannot express. The
  magnitudes agree exactly; the directions do not. Not yet costed.
- ~~**BLOCKING: no closed-loop balance controller**~~ — **built in M21**
  ([ADR-0026](DESIGN_DECISIONS.md)). The baseline is now bounded at ~2 mm mean drift
  over 40 steps, against M17's 25 mm and growing.
- ⚠️ **NEW — the envelope is direction-dependent, and the reduced-order model
  over-promises.** `StepPlant` quotes one number (30.34 mm feet-only) for every
  direction. Measured on a **settled cycle** (M23, [ADR-0028](DESIGN_DECISIONS.md)) —
  M21/M22's figures were taken before the limit cycle and were pessimistic:

  | | predicted | measured worst | achieved |
  |---|---|---|---|
  | feet only | 30.3 mm | **25.3 mm** | **84 %** |
  | with spine | 52.7 mm | **28.9 mm** | **55 %** |

  ⚠️ **The foot-placement model is nearly right; the gap is in the SPINE term.**
  `control.py` books 36.6 mm of static spine authority; measured, the spine buys
  **3.6 mm** of worst-case envelope.
- ⚠️ **NFR15 is NOT demonstrated in simulation** (ADR-0027, corrected by ADR-0028).
  48 mm required, **28.9 mm** measured worst-case, 52.7 mm predicted — a **1.66×
  shortfall**. The spine is in the loop and helps (+14 % worst case at gain 0.2), but
  by gain 0.4 the robot falls at the smallest disturbance tested.
  ⚠️ **This refutes neither the requirement nor the model.** The prediction assumes
  optimal control on one axis; the measurement uses a proportional law.
- ⚠️ **The spine credit is not being spent AT ALL** (M24, [ADR-0029](DESIGN_DECISIONS.md)).
  The proportional assist has **unity loop gain by construction** — the actuator sits
  in its own position feedback path — so even gain 0.2 degrades the *undisturbed*
  baseline 5× (2.15 → 11.43 mm) and 0.5 falls unaided. **M22/M23's "+14 % from the
  spine" is withdrawn**; worst case is 28.9 mm with and without it.
  The motor is not the limit (open-loop ramps survive 300°/s) and slew-limiting does
  not help.
- ⚠️ **And a planned deployment fixes the stability without buying envelope** (M25,
  [ADR-0030](DESIGN_DECISIONS.md)). Deciding once per stance and executing open-loop
  is stable to gain 1.0 and slightly *improves* the baseline — so the fault was the
  structure, not the actuator. But at 0.23 mm resolution it adds **+0.23 mm** to the
  worst direction against a credited 36.6 mm, and at gain 1.0 it *costs* 12 mm in
  another.
- ⚠️ **WHY: the credit is authority in the wrong axis** (M26,
  [ADR-0031](DESIGN_DECISIONS.md)). At the envelope limit the **along-line** DCM
  component is 2–4× the perpendicular one and **nothing controls it** — feet move
  fore-aft, the spine acts laterally. `plant.spine` is a correct lateral figure booked
  against a failure mode that is not lateral. It is **re-scoped, not withdrawn**; the
  defect is the single-axis `StepPlant`, which cannot tell the two apart.
  Also: `ncon = 1` through most of a recovery — the robot is on **one foot**, so the
  support-*line* geometry the model rests on does not hold while it recovers.
- ✅ **SETTLED (M28, [ADR-0033](DESIGN_DECISIONS.md)): NFR15 is ACHIEVABLE, and the
  model was never the problem.** The **viable set** — what *any* controller could
  recover from — is computable in closed form, and it reverses three earlier
  conclusions:

  | | worst direction |
  |---|---|
  | Viable, feet only (exact) | **29.8 mm** |
  | `control.py` feet-only | 30.3 mm (within 2 %) |
  | MuJoCo measured | 28.9 mm (**97 % of optimal**) |
  | Viable, + spine (exact) | **62.7 mm** |
  | NFR15 requires | 48.0 mm |

  The reduced-order model is **not optimistic** (its spine figure is *conservative*),
  the foot-placement controller is **near-optimal**, and the authority to meet NFR15
  **exists**. What remains is a controller that can spend it — now justified work
  with a proven target rather than a hope.
- ⚠️ (superseded reasoning, kept for the record) M27's finding that the free
  along-line actuator exists but delivers little: The free along-line actuator — differential stance-leg extension,
  shifting the CoP along the support line — **does exist** on compliant legs (linear,
  −39.3 mm/mm, 5 of 7 test points keeping two contacts). M21 wrote it off at stiff
  gains and never rechecked. It buys **+1.8 mm** at best while degrading the baseline
  4×.

  | actuator | credited | delivered |
  |---|---|---|
  | Lateral spine | 36.6 mm | **+0.23 mm** |
  | CoP / weight shift | ±109 mm of CoP | **+1.8 mm** |
  | Foot placement | 30.3 mm | 25.3 mm (**84 %**) |

  **Only the actuator the controller was designed around delivers.** That is one fact
  about the controller, not three about the actuators. **Do NOT buy abduction**
  (+528 g) for a controller that cannot use the authority it has. A whole-body QP or
  step-MPC is the prerequisite for settling any of this.
- ⚠️ **UNMEASURED: how much offset the spine can actually hold.** Two attempts gave
  44.0 mm and 16.5 mm because the offset drifts rather than holding, so averaging its
  magnitude reads drift as bias. The 36.6 mm credit is neither confirmed nor refuted.
- ⚠️ **ADR-0019/0020's friction costs** (0.98 + 0.27, the numbers that slowed the
  trot from 67 to 50 cm/s) are still **untested** — but no longer unreachable: the
  harness now holds the robot up long enough to read contact forces.
- The **sway authority was 4 % optimistic** and is now corrected (M20): envelope
  53.90 → **52.72 mm**, NFR15 still met with 4.72 mm of margin.

---

## Recommended order

1. **Buy and weigh a motor** (R1) — largest blast radius, ~£60.
2. **Drag-test a TPU pad** (R2) — half a day, no equipment.
3. **Pick a cell** (R3) — closes NFR6 properly.
4. **Anodise the girdles** (NFR18, ADR-0023) — ~39 K for no mass or power.
5. Then **build electronics/firmware** (§5), which is gated on none of the above.
6. Bench R4/R5 once a leg exists.

Steps 1–3 are perhaps a week of elapsed time and a hundred pounds, and they
convert the three load-bearing assumptions in this project into measurements.

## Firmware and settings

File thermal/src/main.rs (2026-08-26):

// SPDX-License-Identifier: Apache-2.0
// Copyright 2026 Younghyeon Park
//! Prints the R5 thermal report. `cargo run --release` from `thermal/`.

use tomcat_thermal::from_power_py::*;
use tomcat_thermal::*;

fn c(rise: f64) -> f64 {
    AMBIENT_C + rise
}

fn main() {
    let motor = Part::motor();
    let girdle = Part::girdle();

    println!("=== as modelled ===");
    println!(
        "  motor   {:5.1} cm2 skin, Biot {:.4}, tau {:4.1} min",
        motor.area_m2 * 1e4,
        motor.biot(STILL_AIR_H),
        motor.time_constant_min(EMIS_POLISHED, STILL_AIR_H)
    );
    println!(
        "  girdle  {:5.1} cm2 skin, Biot {:.4}, tau {:4.1} min",
        girdle.area_m2 * 1e4,
        girdle.biot(STILL_AIR_H),
        girdle.time_constant_min(EMIS_POLISHED, STILL_AIR_H)
    );
    println!(
        "  centralising 6 motors costs {:.0} % of the rejection area ({:.0} -> {:.0} cm2)",
        100.0 * (1.0 - girdle.area_m2 / (6.0 * motor.area_m2)),
        6.0 * motor.area_m2 * 1e4,
        girdle.area_m2 * 1e4
    );
    println!("  runtime: trot {TROT_RUNTIME_MIN:.1} min, stand {STAND_RUNTIME_MIN:.1} min");

    println!("\n=== front girdle, 6 motors — the boundary that decides it ===");
    println!("  {:22} {:>12} {:>16}", "", "continuous", "one battery");
    for (name, w, mins) in [
        ("trot (21.0 W)", 6.0 * TROT_W, TROT_RUNTIME_MIN),
        ("stand, no brake", 6.0 * STAND_W, STAND_RUNTIME_MIN),
    ] {
        for (fin, e) in [("polished", EMIS_POLISHED), ("anodised", EMIS_ANODISED)] {
            println!(
                "  {name:15} {fin:9} {:8.1} C {:12.1} C",
                c(girdle.equilibrium(e, STILL_AIR_H, w)),
                c(girdle.rise_after(e, STILL_AIR_H, w, mins))
            );
        }
    }

    println!("\n=== airflow sensitivity (girdle, anodised, trot) ===");
    for h in [5.0, 7.0, 15.0, 25.0] {
        println!(
            "  h={h:5.1} W/m2K -> continuous {:5.1} C",
            c(girdle.equilibrium(EMIS_ANODISED, h, 6.0 * TROT_W))
        );
    }

    // The version to trust: pack and girdle as two coupled domains, energy audited
    // by the kernel, runtime emergent rather than taken from elsewhere.
    println!("\n=== coupled discharge, under the kernel's conservation audit ===");
    const BATTERY_WH: f64 = 42.0;
    use tomcat_thermal::from_power_py::TOTAL_W;
    for (fin, e) in [("polished", EMIS_POLISHED), ("anodised", EMIS_ANODISED)] {
        match girdle.discharge(e, STILL_AIR_H, BATTERY_WH, TOTAL_W, 6.0 * TROT_W) {
            Ok(d) => println!(
                "  {fin:9} pack flat at {:5.2} min -> {:5.1} C  \
                 ({:.0} % of the settled rise)",
                d.minutes,
                c(d.rise_k),
                100.0 * d.fraction_of_equilibrium
            ),
            Err(v) => println!("  {fin:9} AUDIT FAILED: {v:?}"),
        }
    }
    println!(
        "  runtime is emergent ({BATTERY_WH} Wh at {TOTAL_W:.1} W), not assumed \
         — power.py says {TROT_RUNTIME_MIN:.2} min"
    );

    println!("\n⚠️  assembly-SKIN temperatures. Windings run hotter, and copper loss");
    println!("    is the only source modelled (ADR-0021), so reality is worse.");
}

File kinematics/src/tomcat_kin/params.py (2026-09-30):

# SPDX-License-Identifier: Apache-2.0
# Copyright 2026 Younghyeon Park
"""Placeholder parameters for the TomCat single-leg model.

IMPORTANT: every numeric value here is a PLACEHOLDER (❓ TBD in
docs/REQUIREMENTS.md). They exist so the model runs end-to-end; they are not
committed design values. Swap them once mechanical design lands.

Conventions
-----------
- SI units throughout: metres, radians, kilograms, newtons, newton-metres.
- Sagittal-plane (2D) model: x forward, z up, hip at the origin.
- A DIGITIGRADE 4-link chain (cats stand on their toes):
      hip -> femur -> stifle/knee -> tibia -> hock/ankle -> metatarsus -> paw.
  The first THREE joints (hip, stifle, hock) are ACTUATED; the paw is a PASSIVE
  distal link held at a fixed rest angle relative to the metatarsus. There is NO
  fourth motor: the actuated joint vector stays q = (q1, q2, q3) (see LegParams).

=====================================================================
MASS BUDGET (M4 — "real mass"): how the 3.0 kg was apportioned  ❓ ALL PLACEHOLDER
=====================================================================
Before M4 every link was MASSLESS and ``whole_body_budget`` lumped EQUAL point
masses at the vertebrae (its own assumption A2 conceded real cats are ~60%
front-heavy). The numbers below replace that with a distributed, front-heavy
budget. They are apportioned, NOT measured — every one is ❓ TBD.

Apportionment rule — REBUILT BOTTOM-UP (review findings F1 + F2, see
mechanical/DESIGN_REVIEW.md). The first version of this budget copied feline
biology (limbs ~24% of body mass) and then TUNED the girdle masses to hit a
60/40 front-heavy split. Both were wrong for this machine:

  * F1 — a biological limb's mass is mostly MUSCLE, and P1/ADR-0003 deliberately
    relocate the muscle (motors) into the girdles. Charging the limbs a
    biological fraction DOUBLE-COUNTS the actuator. A bottom-up count of the
    specced hardware (Al sheaves + CF-tube bones + miniature bearings + cable)
    gives ~80 g/leg bare, ~110 g with margin -- not 200 g.
  * F2 — the 60/40 split was an INPUT tuned into the girdle masses. It is
    properly an OUTPUT of where the hardware actually sits, and the motors do
    NOT sit forward: per ADR-0005 the pelvis carries 19 of them and the shoulder
    only 12.

1. TOTAL = **4.05 kg** -- raised from 3.00 kg once a real motor was sourced
   (see step 3 and docs/notes/motor-reality-check.md). A domestic cat is 4-5 kg,
   so this is if anything MORE biomimetic than the original target; but it was
   forced by hardware, not chosen.
2. LEGS, bottom-up: **0.110 kg** hind / **0.095 kg** fore -> 0.410 kg for all
   four = **13.7%** of body (was 24%). Still proximal-heavy within the leg
   (47.5 / 30 / 15 / 7.5 %) because tendon drive centralises mass.
3. GIRDLES carry their real contents -- motors + one driver board each:
       front  = 6 leg motors x 132 g + head/neck 0.240 + structure 0.090 = **1.122 kg**
       rear   = 7 motors x 132 g + structure 0.110 + tail 0.0098         = **1.0438 kg**
   ⚠️ The rear girdle's SEVENTH motor is the tail's (M102); the head in the
   front girdle is no longer lumped at the mount but placed where it is drawn.
   where 132 g = the SURVEYED REAL PART (SteadyWin GIM3505-9: 120 g motor +
   integrated driver = 131.7 g), NOT the 72 g class target it replaced.
4. SPINE segments = 1.469 kg: 0.130 / 1.2122 / 0.127 kg rear->front.
   The MIDDLE segment dominates because it carries both the ~0.300 kg battery
   AND the SIX spine motors (3 dorsoventral + 3 lateral), which the CAD
   packaging puts in the mid-body bay between the girdles.

   ⚠️ **This said "the 7-motor spine+tail bank" for nine milestones and the
   seventh was the TAIL's.** ADR-0007 bought it; M88 placed it on trunk body 0
   beside the hind leg bank; ADR-0096 found that the trunk's own check counted
   `%d of 18` and could not see it. M102 moved it to the rear girdle, where
   body 0 maps, with the 9.8 g tail it drives -- 141.8 g out of this segment
   and onto that girdle, so the body total does not move.
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

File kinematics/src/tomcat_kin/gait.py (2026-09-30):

# SPDX-License-Identifier: Apache-2.0
# Copyright 2026 Younghyeon Park
"""Parameterized periodic WALK gait generation (quasi-static).

This module turns the static whole-body model (``spine.py`` + ``leg.py``) into
*motion*: a periodic walk that produces per-leg joint-angle trajectories over one
gait cycle by generating a foot trajectory for each leg and running the existing
per-leg inverse kinematics (``LegModel.inverse``) on it. It is the M2 milestone
layer that sits on top of M1's kinematics (see docs/ROADMAP.md).

Frames & conventions
--------------------
- Sagittal plane only: x forward, z up (matches ``leg.py`` / ``spine.py``).
- Foot targets are expressed in each leg's OWN hip/leg frame — the same frame
  ``LegModel.forward`` / ``.inverse`` use (hip at the origin, x forward, z up).
  We never move the world; the body advancing forward shows up as the foot
  sweeping backward (-x) in the hip frame during stance.
- Angles are radians internally; joint vectors are the leg's (q1, q2, q3).
- Gait "phase" is a dimensionless fraction of the cycle in [0, 1); phase wraps at
  1.0 (phase 1.0 == phase 0.0). Time maps to phase via ``phase = (t / period) % 1``.
- Each leg has a phase OFFSET: its local phase is ``(phase - offset) % 1``. A leg
  is in STANCE for local phase in ``[0, duty_factor)`` and in SWING for local
  phase in ``[duty_factor, 1)`` (half-open, so touchdown counts as stance).

Gait timing (the walk)
----------------------
The default is a statically stable, lateral-sequence walk with **duty factor
0.90** and swing windows spaced 0.25 apart. At most one leg swings at a time, so
at least THREE feet are always planted (the classic crawl condition), and because
0.90 > 0.75 the windows do NOT tile: four FOUR-FOOT windows of 15% of the cycle
each open between them.

Those four-foot windows are not incidental — they are the reason duty is 0.90 and
not the textbook 0.75. The lateral spine sway (below) must change sides, and it
can only do so while all four feet are down. At exactly 0.75 one leg touches down
at the same instant another lifts off, the support side flips discontinuously,
and the sway would have to be instantaneous. See ``GaitParams.duty_factor``.

Default per-leg phase offsets (touchdown phase of each leg):

    LF = 0.00,  RF = 0.25,  RR = 0.50,  LR = 0.75

so the liftoff (swing) sequence around the cycle is RF -> RR -> LR -> LF. (The
biological cat lateral-sequence walk LH->LF->RH->RF is the same family; only the
offset-to-leg labelling differs. Any assignment of the offset SET {0, .25, .5,
.75} keeps the >=3-foot support property, and — a measured result, see
tests/test_stability.py — all 24 assignments give the same lateral margin to
within 2 mm. Sequencing is NOT a lever for lateral stability; sway is.)

Lateral sway (M5, ADR-0009)
---------------------------
Three feet down means a SKEWED support triangle, and a mid-sagittal CoM falls
outside it: the default walk is laterally unstable at -21.6 mm however healthy
its fore-aft margin looks. The fix is the actuated lateral spine bend: hold the
spine at ``lateral_amplitude`` toward the SUPPORT side through each 3-foot phase
and traverse across the four-foot windows (``GaitController.lateral_q``). That
recovers a +10.1 mm polygon margin. See ``GaitParams.lateral_amplitude`` for
why 12.5 deg is an optimum rather than a maximum.

Body speed relationship
------------------------
A planted foot sweeps ``stride_length`` backward (in the hip frame) over the
stance duration ``duty_factor * period``. For non-slipping contact the body
therefore advances forward at::

    body_speed        = stride_length / (duty_factor * period)   [m/s]
    distance_per_cycle = stride_length / duty_factor              [m/cycle]

Foot trajectory
---------------
- STANCE (fraction u in [0, 1] through stance): the foot is on the ground and
  moves backward at constant speed from +stride/2 (front, at touchdown) to
  -stride/2 (rear, at liftoff); height held at the nominal ground level::
      x = x_nom + (stride/2) * (1 - 2u)
      z = z_nom
- SWING (fraction v in [0, 1] through swing): a smooth CYCLOID returns the foot
  forward while lifting it, with zero horizontal AND vertical velocity at both
  liftoff and touchdown::
      x = x_nom - stride/2 + stride * (v - sin(2*pi*v)/(2*pi))
      z = z_nom + step_height * (1 - cos(2*pi*v)) / 2
  so lift above ground is 0 at v=0 and v=1 and peaks at ``step_height`` at v=0.5.
- Foot pitch phi is held at ``foot_pitch`` throughout.

Optional spine coupling (off by default)
-----------------------------------------
With ``spine_amplitude > 0`` the controller returns a small sinusoidal
dorsoventral spine bend coupled to the gait phase (a uniform per-segment angle
``spine_amplitude * sin(2*pi*(phase + spine_phase))``) so spine<->gait coupling
can be demonstrated. It defaults OFF (amplitude 0 => the spine is held NEUTRAL,
all-zero angles). NOTE: because foot targets live in the (moving) hip frame, the
spine bend changes where the feet are IN THE WORLD but does NOT change the per-leg
IK solution — it is a demonstration of coupling, not a whole-body foot-placement
controller. Closing that loop (placing feet in a world/ground frame through the
spine) is future work.
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

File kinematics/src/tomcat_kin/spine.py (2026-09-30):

# SPDX-License-Identifier: Apache-2.0
# Copyright 2026 Younghyeon Park
"""Articulated tendon-driven spine + whole-body kinematics (sagittal plane).

This module treats the torso as a SERIAL revolute chain (ADR-0006, principle P2)
in the same 2D sagittal plane as the leg model: x forward, z up. The spine
positions and orients the base each leg hangs from, so the legs no longer swing
from a fixed frame — they hang off a moving, curving body ("whole-body
kinematics").

Frames & conventions
--------------------
- Sagittal plane only: x forward, z up. Lateral bending and axial rotation are
  out of this plane and are NOT modelled (see SpineParams for the 2D-scope note).
- The spine chain is indexed base/rear -> front. Vertebra 0 sits at the base
  (the REAR / pelvic girdle). Traversing the N segments reaches vertebra N (the
  FRONT / shoulder girdle). Anatomical "front" is +x.
- A pose is (x, z, theta): position (m) and frame orientation (rad), theta
  measured CCW from +x.
- Joint angles q = (q_1 .. q_N) are RELATIVE angles. The cumulative direction of
  segment i is theta_base + q_1 + ... + q_i. Positive q rotates CCW (from +x
  toward +z), lifting the outboard spine dorsally; a uniform positive bend curls
  the chain upward into an arched / dorsiflexed ("Halloween cat") posture. This
  matches the leg model's sign convention exactly.

Girdle -> leg composition
-------------------------
Each girdle is a moving frame. A leg's hip origin is placed at a fixed offset in
its girdle frame; the standalone LegModel then runs in that hip frame, and its
foot position is rotated/translated into the world by the girdle pose. Front
legs (shoulder pair) hang off the front girdle, rear legs (pelvic pair) off the
rear girdle.

Whole-body inverse kinematics (M3)
----------------------------------
``WholeBody.inverse`` runs that composition BACKWARDS: given a foot pose in the
WORLD frame and the spine angles, it undoes the girdle/hip transform and solves
the per-leg IK, so a foot can be commanded to a fixed world position and the leg
angles absorb the spine bend (feet placed "through" the moving spine). See its
docstring for the frame chain and the 2D transform math.

Modelling assumptions / limitations
-----------------------------------
- 2D sagittal only: the four legs' left/right lateral (y) offset is out of plane
  and ignored, so in this projection the two front legs share a mount pose (and
  likewise the two rear legs). This is a real limitation for anything involving
  roll, yaw, lateral bend, or the righting-reflex twist.
- Rigid links and a frictionless idealisation are inherited from the leg/tendon
  models.
- MASS (M4): the kinematics themselves are mass-free, but the body now carries a
  real distributed mass budget (params.py) and ``WholeBody.center_of_mass``
  reports the posed whole-body / sub-assembly CoMs. That is QUASI-STATIC ONLY —
  gravity and CoM geometry, no velocities, accelerations or inertia tensors. The
  literature's Mass-Mass-Spring result (leg mass bends a compliant trunk) is
  therefore still NOT captured: that needs the dynamics milestone.
"""

from __future__ import annotations

from dataclasses import dataclass, field
from enum import Enum
import math
from typing import Mapping

import numpy as np

from .params import (
    SpineParams,
    LegParams,
    DEFAULT_SPINE,
    DEFAULT_LEG,
    DEFAULT_FORELEG,
    DEFAULT_HINDLEG,
)
from .leg import LegModel, KneeConfig, UnreachableError
from .mass import (
    ComResult,
    QuarterMasses,
    combine,
    leg_com,
    quarter_masses,
    spine_chain_com,
)


def _rot(theta: float) -> np.ndarray:
    """2x2 rotation matrix for a CCW rotation by theta (rad)."""
    c, s = math.cos(theta), math.sin(theta)
    return np.array([[c, -s], [s, c]])


class Girdle(Enum):
    """The two limb-bearing girdles the spine spans."""

    FRONT = "front"  # shoulder girdle (front end of the chain, +x)
    REAR = "rear"    # pelvic girdle (base / rear end of the chain)
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

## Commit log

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2026-07-27 Add articulated spine + whole-body kinematics (ADR-0006)
    Serial tendon-driven spine as a sagittal revolute chain (SpineModel):
    FK to both girdle frames and the transform placing each leg's hip
    origin on the curving base. WholeBody composes the spine + four legs;
    TendonMap generalized to any joint count with from_spine() so spine
    cables get the same antagonistic torque<->tension treatment as legs.
    Seed 3 segments (placeholders). 34 tests pass; demo shows an arched
    back lifting the front girdle and carrying the front foot.
    [demo.py, params.py, spine.py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]
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2026-07-27 Complete M1 kinematics + spine/tail spec + stiffness derivation
    tomcat-kinematics: add commandable co-contraction bias T_bias to the
    tendon map (ADR-0002; default reproduces prior pretension numbers) and
    a combined whole-body static budget (whole_body_budget.py) over
    stand/arch/land reporting per-tendon tension, per-motor torque, and a
    30-motor total (24 legs + 6 spine, antagonistic). 48 tests pass.
    tomcat-research: document the axial(N/mm)->rotational(N·m/rad) geometry
    bridge and per-axis stiffness seeds (~1.0 N·m/rad extension) + confirmed
    AIC/tension seeds, in LITERATURE_REVIEW.md.
    tomcat-mechanical: mechanical/SPINE_TAIL_SPEC.md — 3-segment tapered
    spine geometry, tendon routing, m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
    [demo.py, params.py, tendon.py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]
2026-07-27 Reconcile spine params from mechanical + research findings
    Lead integration of the M1 specialist outputs into params.py:
    - segment_lengths -> tapered (0.075,0.065,0.055) per SPINE_TAIL_SPEC.
    - spine joint_moment_arm 0.020 -> 0.030 m (mechanical): cuts worst-case
    spine cable tension ~535 N -> ~383 N, toward the 20-70 N band.
    - spine spring_stiffness -> ~1.0 N·m/rad from the axial->rotational
    bridge (research; order-of-magnitude, sagittal axis).
    - clarify pretension (mechanical slack floor) vs. the AIC control bias
    T_bias (~19.6 N) passed at runtime.
    Fix test_straight_spine_base_joint_symmetric_zero to build a uniform
    spine explicitly (the exact base-torque cancellation is specific to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
    [params.py, test_whole_body_budget.py]
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2026-07-27 Add control interface schema + electronics board outline (M1 Phase 2)
    tomcat-firmware: firmware/INTERFACE.md + firmware/include/tomcat_can_schema.h
    (compiles -Wall -Wextra -std=c11). Two layers: SBC<->RT setpoints/telemetry
    (fields aligned with TendonSolution: motor-side tension, t_bias, stiffness)
    and RT<->drivers over CAN-FD (11-bit priority IDs, 16/20-byte command/telem
    frames). Bus-load math: ~33 motors at 5-6 nodes/segment -> 6-7 segments
    (matches ADR-0005). 16-bit fault bitfield + 3-tier safety wiring.
    tomcat-electronics: electronics/BOARD_OUTLINE.md. One universal FOC
    smart-driver board with a dual (current-estimate + DNP load-cell) tension
    front-end so either ADR-0004 outcome ships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
    [tomcat_can_schema.h]
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2026-07-27 M2: walk gait generator on the whole-body model
    Add kinematics/gait.py: GaitParams, cycloid-swing foot_target, and a
    GaitController that runs per-leg IK over the cycle and flags unreachable/
    out-of-limit poses. Statically-stable lateral-sequence walk (duty 0.75 ->
    exactly 3 feet down), optional gait-coupled dorsoventral spine oscillation
    (off by default). Demo prints a full cycle; 67 new tests (133 total).
    Mark M2 done in the roadmap; whole-body foot placement deferred to M3.
    [demo.py, gait.py]
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2026-07-28 M3: whole-body foot placement (spine<->gait loop closed)
    Feet placed in a world/ground frame, per-leg IK solved through the moving
    girdle (world <- girdle(spine_q) <- hip <- foot). Add WholeBody.inverse /
    inverse_pose (LegIKSolution) and a WholeBodyGaitController that holds stance
    feet planted in the world while the legs compensate for spine motion; the
    existing hip-frame GaitController stays the default. Verified: stance foot-
    target span 0.000 mm under a spine oscillation, FK error ~0. 25 new tests
    (158 total). Mark M3 done in the roadmap.
    [demo.py, gait.py, spine.py]
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2026-07-28 Add 3D packaging study: motors, tendons, joints in the skeleton
    tomcat_packaging.py places one motor per driven tendon clustered in the
    girdles (P1), routes tendons from each spool along the limb/spine to its
    joint, and puts pulleys at every joint at real moment-arm radii; girdle
    housings are SIZED to enclose the motor banks (a real fit check).
    Fit findings: 24 motors; shoulder girdle 70x142x51, pelvic 70x142x91 mm.
    Surfaces a genuine packaging issue -- lateral-axis motors make the girdles
    ~142 mm wide (> 96 mm track) and the pelvic girdle the density/thermal
    hot-spot; options: reorient motors, spread the bank, or use the variable-
    radius-pulley reduction. STEP + render tracked; STL gitigno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
    [tomcat_packaging.step]
2026-07-28 Digitigrade 4-link leg (3 actuated joints + passive paw)
    Extend LegModel from a planar 3R to a 4-link digitigrade chain
    (femur/tibia/metatarsus/paw) matching real cat anatomy, WITHOUT adding a
    motor: the paw is a passive distal link at a fixed rest angle off the
    metatarsus, so the actuated joint vector stays q=(hip,stifle,hock) and the
    3-motor/leg architecture is unchanged. forward/inverse now work in the
    paw-tip (ground-contact) pose; joint_positions returns 5 points; Jacobian
    stays 3x3. Retune gait defaults for the shorter digitigrade reach.
    163 tests pass. Reference: Felis silvestris skeleton plate.
    [gait.py, params.py]
2026-07-28 CAD: digitigrade legs + fore/hind opposite fold (Felis silvestris ref)
    Rebuild the skeleton and packaging CAD on the new 4-link digitigrade leg
    (auto: joint_positions now 5 points -> 4 bones/leg = femur/tibia/
    metatarsus/paw). Front legs mirror the rear so the fore- and hind-limbs
    fold in opposite directions, per the Felis silvestris skeleton plate the
    user supplied. Fix packaging pulley/tendon unpacking for the 5-point
    chain (pulleys on the 3 actuated joints; paw passive). Update the CAD
    README (link lengths, digitigrade note, envelopes). STEP + renders
    tracked; STL gitignored.
    [tomcat_packaging.step, tomcat_skeleton.step]
2026-07-28 Widen hock limit + paw angle for a proper digitigrade crouch
    params.py: paw_angle 30->55 deg (anatomical toe-break), hock (ankle)
    joint limit +/-60 -> +/-90 deg (was the binding cap on stance depth).
    Re-tune gait to the new geometry (foot_pitch 5->0 deg = paw flat on the
    ground, nominal_foot (0.225,-0.10)->(0.20,-0.13), stride 0.06->0.05);
    mid-stance now hock held ~57 mm above a flat paw. Fix one unreachable
    hardcoded whole-body IK test target; 163 tests pass. CAD stance set to
    paw-flat (FOOT_PITCH 0) and re-rendered. Binding joint is now the hip,
    not the hock. Anatomical reference: Felis silvestris plate.
    [tomcat_packaging.step, tomcat_skeleton.step]
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2026-07-29 M4: real mass — CoM, static stability margin, distributed gravity
    Replace the massless / equal-lumped placeholder with a distributed,
    front-heavy mass budget totalling 3.0 kg (forequarters 1.798 kg = 59.9%),
    apportioned by a documented lever rule; front girdle absorbs head+neck.
    New mass.py (per-link/segment CoMs, quarter_masses) and stability.py
    (fore-aft support interval, margin, centering_shift); WholeBody gains
    center_of_mass / mass_budget; both gait states report CoM + margin;
    whole_body_budget assumption A2 rewritten to use the real distribution.
    Effect on the spine budget: quiet-stand base-joint torque grows ~3.9x and
    becomes the WORST spine joint (the front half cantilevers off it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
    [demo.py, gait.py, mass.py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]
2026-07-29 Fix the M4 stability defect: adopt the anatomical negative-knee fold
    Root cause of M4's unstable walk was the knee-branch/joint-limit
    convention, NOT the link lengths. On the inherited POSITIVE-knee branch
    (stifle >= 0) planting a paw under its own hip demanded a ~+167 deg hip,
    so the gait was pushed to a +0.20 m nominal foot and every foot landed
    ahead of the trunk. On the NEGATIVE (anatomical digitigrade) fold the same
    pose is ordinary at hip -71 deg.
    - LegParams limits rewritten for the negative fold: hip +/-120, stifle
    -150..0 (negative-only, encoding the fold structurally), hock -30..+150.
    - KneeConfig default flipped to FLEXED_NEGATIVE across leg, gait, spine,
    torque_budget and wh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
    [tomcat_packaging.step, tomcat_skeleton.step]
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2026-07-29 Resolve review F1+F2: rebuild the mass budget bottom-up
    Rebuild the 3.0 kg budget from the specced hardware with motors in their
    real ADR-0005 clusters, replacing the biological 24% limb fraction and the
    TUNED 60/40 front-heavy split. The split is now an OUTPUT, not an input.
    all four legs 720 g (24%) -> 410 g (13.7%)
    front girdle 700 g -> 762 g (12 motor channels + head/neck)
    rear girdle 280 g -> 794 g (19 channels) -- now the heavier one
    fore/hind 59.9/40.1 -> 51.2/48.8 (near-balanced)
    body CoM x +130 mm -> +102 mm (19 mm rearward)
    worst margin +46.5 mm -> +27.4 mm
    stand spine T 24 N -> 12 N
    The walk REMAINS st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
    [params.py, test_mass.py, test_whole_body_budget.py]
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2026-07-29 Resolve review F4: stand the motors upright to fit the girdles
    F4 was a motor ORIENTATION problem, not a volume problem. Every motor was
    laid axis-along-Y, so its 28 mm body + 7 mm spool projected SIDEWAYS from
    banks already sitting at y=+/-42 -- giving a 142 mm-wide girdle against a
    96 mm leg track, and a 91 mm-tall pelvic girdle.
    Standing the motors upright (axis-along-Z) puts that 28 mm length into
    girdle HEIGHT, where there is room, and reduces the footprint to a grid of
    circles. With compact 3x2 banks pulled inboard to y=+/-21 and the
    spine/tail bank offset rearward in x:
    girdle width 142 mm -> 87 mm (inside the 96 mm track)
    pelvic height 91 mm -> 52 mm (now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
    [tomcat_packaging.step]
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2026-07-29 Fix foreleg anatomy: elbow bends back, both paws point forward
    User observed the leg shape did not match a cat. Diagnosis: the HIND leg was
    already correct (stifle +56 mm forward, hock -15 mm back and 57 mm above the
    toes -- the propulsion Z), but the FORE leg was drawn by MIRRORING the whole
    limb fore/aft. That flips the paw too, so the front paws pointed BACKWARD at
    the tail. A real cat has both paws forward; only the middle joint's bend
    direction differs -- elbow back, stifle forward.
    Fix, done as anatomy rather than a drawing trick:
    - DEFAULT_FORELEG gets its OWN joint limits with a POSITIVE elbow range
    (shoulder -170..+30, elbow 0..+150, carpus -30..+150), sized from the
    demanded g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
    [tomcat_packaging.step, tomcat_skeleton.step]
2026-07-30 Detailed skeletal pass: bone form, joint structure and axis orientation
    Replace the capsule massing model with real skeletal detail, following the
    public-domain ANATOMY.md reference and the cat formula C7/T13/L7/S3/Ca~20.
    Bone FORM
    - long_bone(): shaft with expanded CONDYLES at each end, not a plain capsule.
    The flare is where a joint bearing seats and a pulley gets its arm.
    - plate(): flat bones (scapula, ilium, ischium) as tilted sagittal blades.
    - vertebra(): centrum + spinous + transverse processes, drawn for all ~20
    presacral vertebrae. Thoracic spines sweep BACK, lumbar sweep FORWARD,
    meeting at the anticlinal vertebra as in a real cat.
    - ribcage(): 8 C-curved rib pairs closing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
    [tomcat_skeleton.step]
2026-07-30 Crouch the stance to a cat-like 63% extension; fix front paws below ground
    User observed the legs looked too straight. Measured rather than eyeballed:
    hip-to-paw was 70% of leg reach, where a standing cat sits at ~55-65%.
    Deepening the crouch is nearly FREE, which the torque sweep showed:
    - HIP torque is unchanged by crouch depth -- a vertical support force
    produces moment only from the foot's HORIZONTAL offset.
    - HOCK torque is unchanged too -- it is fixed by the paw-flat constraint
    and the 55 deg passive paw angle.
    - Only the STIFLE loads up (0.14 -> 0.34 N.m at trot), far below the
    binding hip/hock, so ADR-0008's motor sizing is untouched.
    Adopted nominal_foot z -0.19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
    [tomcat_packaging.step, tomcat_skeleton.step]
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2026-07-30 3D geometry: real support polygon exposes lateral instability (F7)
    First step of the 3D move, chosen deliberately: 3D GEOMETRY, not 3D actuation.
    Giving the legs their real lateral track offsets costs NO motors (they do not
    move laterally) but makes the true ground-plane support polygon computable --
    closing the caveat every prior document carried, that a 2D sagittal interval is
    "necessary but not sufficient".
    It disagrees with the 2D result, sharply:
    2D sagittal interval : +24.6 mm worst -> stable at every phase
    TRUE support polygon : -28.7 mm worst -> UNSTABLE for ~half the cycle
    With three feet down the support triangle is skewed to one side while the CoM
    sits on the mid-sagittal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
    [gait.py, spine.py]
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2026-07-30 M5: lateral spine DOF -- the walk is finally stable in 3D, and friction sets its speed
    Implements ADR-0009's lateral bend DOF and wires it into the gait. The default
    walk goes from -25.4 mm (laterally UNSTABLE) to +8.4 mm polygon margin, while
    its fore-aft margin was a healthy +32.7 mm throughout -- which is exactly why
    the 2D check could never be trusted alone.
    Model:
    - SpineModel.lateral_vertebra_xy / lateral_segment_com_y -- planar chain in x-y
    - WholeBody.center_of_mass_y -- includes the fore-leg mass riding with the
    front girdle. Reproduces ADR-0009's predicted authority exactly (42.8 mm@15deg)
    - GaitController.lateral_q / support_side / lateral_slew_rate
    - support_polygon now takes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
    [demo.py, gait.py, params.py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]
2026-07-30 ADR-0009 follow-up: size the lateral drive, and fix a 347 g hole in the mass model
    M5 proved the three motors ADR-0009 added were NEEDED. This checks they are
    SUFFICIENT -- and finding out required fixing the mass model, which turned out
    to be wrong in a way that had been hiding since before the motor down-select.
    1. The lateral drive was never sized. WholeBody.lateral_spine_loads now does it.
    The load is INERTIAL, not gravitational: the lateral bend axis is VERTICAL, so
    gravity exerts no moment about it and HOLDING a sway is nearly free. What
    costs torque is REVERSING it in the crossover window. Base joint (it swings
    the whole forequarters): 2.21 N.m -> 110 N cable -> 0.884 N.m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
    [tomcat_packaging.step]
2026-07-30 M6 dynamics: the quasi-static answers were wrong, and the 72 g motor does not exist
    Closes the three open items. Each one overturned something already published.
    === 1. THE MOTOR (docs/notes/motor-reality-check.md) ===
    ADR-0008's mass closure rode on a ~72 g motor at ~1.1 N.m. Surveying the real
    market: the lightest purchasable part meeting that torque is ~120 g -- SteadyWin
    GIM3505-9, 0.71/1.95 N.m at 9:1, 131.7 g with driver, Kt 0.35 N.m/A.
    Torque DENSITY was never the bad assumption (the real part beats the implied
    15.3 N.m/kg). The problem is that motors come in discrete sizes, and the
    smallest one clearing the bar is ~2x the capability needed. So:
    NFR5 raised 3.0 -> 4.05 kg.
    It c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
    [tomcat_packaging.step]
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2026-07-30 M7: the trot works -- 67 cm/s, and a second C1 defect found the same way as the first
    M6 left the statically stable crawl capped at 1.1 cm/s and concluded a dynamic
    gait was no longer optional. This is that gait, and it reaches cat-like speed
    inside the actuator envelope.
    gait.trot_params() -- diagonal pairs, duty 0.50, ~67 cm/s (60x the crawl)
    feasible and thermally sustainable to ~96 cm/s
    A trot degenerates the support from a POLYGON to a LINE, so support_polygon and
    zero_moment_point correctly REFUSE to evaluate -- a line has no interior. Added
    the physics that does apply, in dynamics.py: line_balance (inverted-pendulum
    offset, capture point/DCM, unbalanceable moment), trot_sweep,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
    [demo.py, gait.py]
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2026-07-31 M8: closed-loop balance -- the trot survives a 74 mm push, and reach is what limits it
    M7 closed on an honest caveat: the trot was an OPEN-LOOP consistency check. It
    showed the error STARTS at zero, not that it stays there -- and the trot is an
    inverted pendulum with omega*T = 1.17, so any deviation is multiplied by 3.2
    every step and 339 over five. Nothing in the model arrested it. This closes that.
    control.py -- step-to-step DCM plant, the placement law, and the two
    measurements that say what it is worth.
    === THE LAW ===
    Working in the DCM (xi = c + c_dot/omega) makes the plant first-order,
    xi_dot = omega(xi - p), so balance collapses to one placement per touchdown:
    p = nominal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
    [control.py, demo.py, test_control.py]
2026-07-31 M9: the lateral spine is the trot's main balance actuator -- and M8's envelope was 2.3x too big
    Set out to close the two gaps M8 named -- sensing LATENCY and step RETIMING.
    Chasing them turned up an error in M8's headline number, and then a much better
    actuator than the one I was tuning.
    === THE CORRECTION (my own, from last commit) ===
    The DCM is measured PERPENDICULAR to the diagonal support line, and that
    direction is ~90% LATERAL. M8 used the leg's raw FORE-AFT reach as the placement
    authority. But the legs are sagittal-only -- abduction was rejected in ADR-0009
    and the track is fixed at +/-48 mm -- so a fore-aft foothold shift buys
    perpendicular authority only through its 0.44 project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
    [control.py, demo.py, test_control.py]
2026-08-05 M10: both M9 follow-ups close as NOT NEEDED -- the spine was under-counted, not the limit
    M9 left two questions, both expected to cost motors: revisit leg ABDUCTION (the
    ADR-0009 rejection was argued against a static-stability requirement that no
    longer applies), and consider a FASTER SPINE DRIVE (NFR2f was sized for the
    righting reflex, not balance). Neither is needed, and the reason is that M9
    under-counted the hardware already fitted.
    === THE CORRECTION (mine, from last commit) ===
    M9's spine authority clamped the traverse with NFR2f's 119 deg/s. That is a
    REQUIREMENT FLOOR set by the ADR-0007 righting reflex -- not a capability. The
    real joint rate is:
    380 rpm motor x (8 mm spool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
    [control.py, demo.py, test_control.py]
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2026-08-05 M11: allocate the latency budget -- and the electronics turns out not to be the bottleneck
    M9/M10 left two requirements that no subsystem owned: NFR12 (<=20 ms balance
    latency) and NFR11 (<=3 mm DCM accuracy). Allocating the latency turned the
    calculation inside out.
    === LATENCY IS NOT AN INDEPENDENT PARAMETER ===
    A bigger disturbance needs a bigger foothold correction. A bigger correction takes
    the leg LONGER to execute. And that time IS the staleness of the information the
    controller committed on. Correction size sets latency, sets the envelope, bounds
    the correction -- it has to be solved as a FIXED POINT, which
    control.self_consistent_envelope() now does.
    pipeline (contact + estim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
    [control.py, test_control.py]
2026-08-07 M12: model the actuation ramp, cost abduction -- and state the requirement that was missing
    Closes M11's two follow-ups. Underneath them sat a gap neither had named.
    === THE RAMP: MODELLED, AND IT BARELY MATTERS ===
    Replacing constant velocity with a trapezoidal accel/cruise/decel profile moves
    the envelope only 59.2 -> 57.0 mm (-4%). M11's caveat was over-cautious. Another
    P1 dividend: at 95 g the leg has ~107 g of foot acceleration available, so the
    move is SPEED limited, not acceleration limited. The ramp costs ~10% on a
    full-scale correction but ~50% on a short one, which never reaches cruise.
    A trap worth recording: computing that limit by driving EVERY joint at peak
    torque reports ~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
    [control.py, test_control.py]
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2026-08-07 M14: the spine assist is not free -- it costs ground friction, reinstating a withdrawn requirement
    Set out to model the spine's reaction torque, flagged since ADR-0014 as "an
    instantaneous bounded CoM offset, ignoring its own dynamics". The first thing I
    checked turned out to be more basic than the reaction torque, and more
    consequential.
    === THE PHYSICS THAT WAS MISSED ===
    Bending the spine is INTERNAL motion, and internal motion cannot move the
    whole-body CoM. Moving the CoM RELATIVE TO THE PLANTED FEET requires a horizontal
    GROUND REACTION -- i.e. friction. control.py had been adding spine_assist straight
    to the DCM, free of charge.
    mu_spine >= 4d/(t^2 g), ON TOP of what the gait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
    [control.py, test_control.py]
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2026-08-08 M18 (dualis 0.2): audit the energy books, and find what the hand-comparison missed
    dualis went 0.1.0 -> 0.2.0. Checked what actually changed rather than assuming:
    mostly ergonomics (&str names, Box<dyn Domain> delegation, as_field), plus one
    semantic change -- Exchange::take became take_share(HEAT, dt) for multirate
    subcycling. It falls back to take() when no scheduler interval is set, which is
    exactly how this crate drives it, so no result should move.
    Verified by re-running rather than by reading the diff: every M18 number is
    byte-identical on 0.2.0, and the 7 original assertions still pass.
    dualis-mechanics did NOT gain articulated multibody dynamics -- still N-body
    plus penalty contact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
    [lib.rs, main.rs]
2026-08-08 M18 correction: the 53 min time constant was convection-only
    Preparing an upstream issue about dualis-thermal's equilibrium_rise made me
    check the neighbouring function, and it invalidated a claim I published.
    LumpedMass::time_constant is C/(hA) -- convection only. It returns the SAME
    number whatever the emissivity, and this crate's own Environment::loss_from
    docs say radiation "is not negligible ... leaving it out halves the loss".
    Measured from the transient (which does include radiation):
    quoted measured vs 30.2 min runtime
    polished 53.0 min 46.6 min outlasts it
    anodised 53.0 min 25.6 min SHORTER than it
    So "the girdle's 53 min time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
    [lib.rs]
2026-08-08 M19 (dualis 0.3): the winding runs 7.7 K above the skin -- the caveat, answered
    All three upstream issues were fixed and 0.3.0 shipped. Checked what that
    means here rather than assuming.
    #1 (radiation) landed: equilibrium_rise now solves the quartic and agrees with
    the stepped transient to three figures (88.7 = 88.7, 49.9 = 49.9), and
    time_constant carries a linearised radiative term so it finally moves with
    emissivity -- 49.2 min polished vs 29.9 anodised, where 0.2 said 53.0 for
    both. The M18 correction in d26de7e is independently confirmed: a bare girdle
    outlasts the pack, an anodised one does not.
    The upgrade also silently broke two of my own helpers, which is worth naming:
    - time_con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
    [lib.rs, main.rs, winding.rs]
2026-08-09 M20a: the sway authority was 4% optimistic -- the fore legs are not at the spine tip
    M17 ran a rigid trunk, so it could only test the feet-only envelope. The spine
    supplies 22.7 mm of the ~53 mm headline, which meant 44% of the number NFR15
    is checked against sat outside the simulation entirely. Adding the three
    lateral spine joints to the MJCF was meant to close that gap. It found a bug
    first.
    The MuJoCo chain -- rear girdle -> 3 spine segments -> front girdle, with the
    fore legs riding the far end -- disagreed with WholeBody.center_of_mass_y by
    1.75 mm at full ROM. Everything else in this model matches to 1e-9, so a
    1.75 mm gap in the quantity that IS the balance authority was worth chasi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
    [control.py, spine.py, test_control.py]
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

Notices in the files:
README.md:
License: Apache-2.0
